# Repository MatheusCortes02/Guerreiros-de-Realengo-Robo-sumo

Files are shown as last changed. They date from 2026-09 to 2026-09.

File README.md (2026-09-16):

# Guerreiros de Realengo · robô de mini sumô

Robô **autônomo** de mini sumô (base de até 10 × 10 cm e até 500 g) do grupo **Guerreiros de Realengo** para a **InovaWeek da UVV**. Ninguém dirige o robô: o juiz dá o **START** e o **STOP** pelo controle, e ele procura o adversário e ataca sozinho.

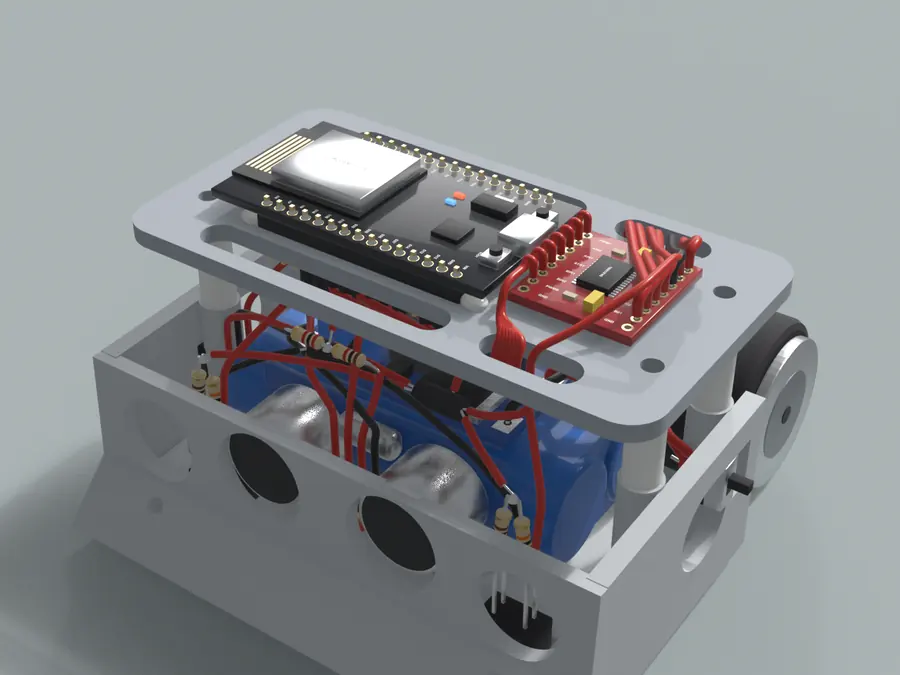
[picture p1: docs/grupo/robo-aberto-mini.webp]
Robô aberto: ESP32 e ponte H em cima da plataforma, fiação embaixo


## Manual de montagem

### [matheuscortes02.github.io/Guerreiros-de-Realengo-Robo-sumo/](https://matheuscortes02.github.io/Guerreiros-de-Realengo-Robo-sumo/)

O site é um **manual no estilo LEGO**, feito para ser seguido na bancada pelo celular:

- **69 passos em 13 blocos**, uma ação por passo;
- **blocos em cards**: entre num bloco e passe os passos um por tela, com botões grandes, deslizar para o lado e continuar de onde parou;
- a primeira tela de cada bloco mostra **os fios que ele usa, já com o tamanho de corte**;
- em cada passo, a **imagem do Blender** com a peça em tamanho real, o **número de cada fio** em cima dele e uma **lupa** com o detalhe;
- avisos do que **queima** se ligar errado e o que **conferir com o multímetro** antes de seguir;
- **vídeo da montagem** com capítulos por bloco, **lista de corte**, **ligações por peça** e **achar fio** pelo número da fita;
- duas versões: a **padrão**, com fios coloridos e tudo soldado do zero ([index.html](https://matheuscortes02.github.io/Guerreiros-de-Realengo-Robo-sumo/)), e a **do grupo**, só com fio vermelho e preto e com sonar, receptor e motores já soldados ([grupo.html](https://matheuscortes02.github.io/Guerreiros-de-Realengo-Robo-sumo/grupo.html));
- **português e inglês** pelas bandeiras no topo ([en.html](https://matheuscortes02.github.io/Guerreiros-de-Realengo-Robo-sumo/en.html) · [grupo-en.html](https://matheuscortes02.github.io/Guerreiros-de-Realengo-Robo-sumo/grupo-en.html)) e **tema claro e escuro** pelo ícone de sol e lua.

### Manual em texto para perguntar a um chat

A pasta [`docs/montagem-texto/`](docs/montagem-texto/) tem o mesmo manual em texto puro, gerado das mesmas fontes do site, para baixar o ZIP do repositório e enviar a um chat de IA no dia da montagem:

| Arquivo | Conteúdo |
|---|---|
| `00-LEIA-PRIMEIRO.txt` | como usar, instruções para o assistente, convenções, onde fica cada peça, alimentação, regras e pontos não confirmados |
| `01-montagem-versao-colorida.txt` | passo a passo completo da versão colorida, com imagem, peças, fio a fio (de onde, para onde, corte, caminho), avisos e conferências |
| `02-montagem-versao-grupo.txt` | o mesmo para a versão do grupo (fio vermelho e preto; sonar, receptor e motores já soldados) |
| `03-fios-lista-completa.txt` | os 36 fios com cor em cada versão, bitola, corte e passos em que aparecem |
| `04-ligacoes-por-peca.txt` | cada peça furo por furo e os 30 pinos do ESP32 contados da ponta do USB |
| `05-conferencias-multimetro.txt` | o que tem que apitar, o que não pode apitar e as tensões da primeira vez ligado |
| `06-firmware-e-gravacao.txt` | pinos do código, gravação, modo teste e modo luta |

## Equipe

Eduardo Nascimento · Gabriel da Silva · Gustavo Nunes · Kaike Panetto · Matheus Cortes

## Como o robô está montado

| Onde | O que fica |
|---|---|
| Frente, embaixo | 2 sensores de borda **TCRT5000 de 4 pernas**, colados nas janelas do piso |
| Frente | sonar **HC-SR04** nos dois furos do meio |
| Lateral direita | receptor do juiz **dentro do furo redondo**, bolinha para fora (lado oposto da chave) |
| Baia | bateria 2S 7,4 V com velcro · regulador **LM2596 colado em cima da bateria** |
| Lateral esquerda | chave deslizante **SS12D00** (3 pinos) |
| Trás | caixa com 2 motores N20 e rodas |
| Plataforma (**+17 mm**: espaçador de 12 mm com um de 5 mm em cima) | **ponte H TB6612** à esquerda · **ESP32** à direita, **apoiado na plataforma com os pinos atravessando dois rasgos** e o **USB virado para a esquerda** |

Esquerda e direita são sempre do robô: sonar apontando para longe de você.

### Alimentação

- **Bateria (+)** vai por dois caminhos: fio **3** direto ao **VM da ponte H** (motores) e fio **1** ao pino do meio da chave.
- A chave **SS12D00 aguenta 0,5 A**, por isso liga **só a eletrônica**: fio **2** até o IN+ do LM2596. A eletrônica puxa uns 0,2 A; os motores, até 3 A, não passam por ela.
- **LM2596** ajustado em **5,00 V** alimenta o VIN do ESP32 (fio 10) e o sonar (fio 12).
- O **3V3 do ESP32** vai a uma **emenda amarela** (fio 14) que alimenta os dois sensores de borda, o receptor e o VCC da ponte H.
- **GND** não é um fio só: o − da bateria vai à ponte H (4) e ao LM2596 (5); a saída do LM2596 vai ao ESP32 (11) e ao sonar (13); o outro GND do ESP32 vai a uma **emenda preta** (15) com os sensores, o receptor e o divisor do sonar.
- Com o cabo USB ligado, a chave fica em **DESLIGA**. Para guardar o robô, desconecte a bateria.

### Os 16 pinos usados no ESP32

Cada fio é soldado **na ponta do pino, por baixo da plataforma**, com termorretrátil. Por baixo não aparece nenhum nome: conte a partir da ponta do USB (o 1º da fileira da frente é o VIN; o 1º da de trás, o 3V3). Os 7 fios da ponte H descem pelo rasgo R2.

| Pino | Fileira | Posição a partir do USB | Fio | Vem de |
|---|---|---|---|---|
| VIN | frente (EN … VIN) | 1º | 10 | LM2596 · OUT+ |
| GND | frente (EN … VIN) | 2º | 11 | LM2596 · OUT− |
| D13 | frente (EN … VIN) | 3º | 31 | ponte H · STBY |
| D14 | frente (EN … VIN) | 5º | 34 | ponte H · PWMB |
| D27 | frente (EN … VIN) | 6º | 29 | ponte H · AIN2 |
| D26 | frente (EN … VIN) | 7º | 30 | ponte H · AIN1 |
| D25 | frente (EN … VIN) | 8º | 28 | ponte H · PWMA |
| D33 | frente (EN … VIN) | 9º | 33 | ponte H · BIN2 |
| D32 | frente (EN … VIN) | 10º | 32 | ponte H · BIN1 |
| D35 | frente (EN … VIN) | 11º | 24 | sensor direito · perna C |
| D34 | frente (EN … VIN) | 12º | 23 | sensor esquerdo · perna C |
| 3V3 | trás (D23 … 3V3) | 1º | 14 | emenda amarela |
| GND | trás (D23 … 3V3) | 2º | 15 | emenda preta |
| D5 | trás (D23 … 3V3) | 8º | 25 | sonar · TRIG |
| D18 | trás (D23 … 3V3) | 9º | 26B | resistor 1 kΩ |
| D19 | trás (D23 … 3V3) | 10º | 27 | receptor · OUT |

### Lista de corte

Comprimentos medidos no modelo 3D com a disposição real e com sobra (caminho + 15% + 20 mm; +40 mm nos fios que ligam a baia à plataforma, para dar para soldar com a plataforma virada). Total: **1050 mm de 22 AWG** e **2660 mm de 26 AWG**.

| Fio | Cor | Bitola | Corte | De | Para | Passa por |
|---|---|---|---|---|---|---|
| 1 | vermelho | 22 AWG | 60 mm | conector da bateria · + | chave · COM | embaixo da plataforma |
| 2 | vermelho | 22 AWG | 60 mm | chave · P1 | LM2596 · IN+ | embaixo da plataforma |
| 3 | vermelho | 22 AWG | 120 mm | conector da bateria · + | ponte H · VM | sobe pelo rasgo R4 |
| 4 | preto | 22 AWG | 120 mm | conector da bateria · − | ponte H · GND | sobe pelo rasgo R4 |
| 5 | preto | 22 AWG | 50 mm | conector da bateria · − | LM2596 · IN− | embaixo da plataforma |
| 6 | cinza | 22 AWG | 160 mm | motor esquerdo | ponte H · A01 | furo Ø6 da tampa e rasgo R4 |
| 7 | cinza | 22 AWG | 160 mm | motor esquerdo | ponte H · A02 | furo Ø6 da tampa e rasgo R4 |
| 8 | branco | 22 AWG | 160 mm | motor direito | ponte H · B01 | furo Ø6 da tampa e rasgo R4 |
| 9 | branco | 22 AWG | 160 mm | motor direito | ponte H · B02 | furo Ø6 da tampa e rasgo R4 |
| 10 | laranja | 26 AWG | 130 mm | LM2596 · OUT+ | ESP32 · VIN | sobe por baixo da plataforma até a ponta do pino |
| 11 | preto | 26 AWG | 120 mm | LM2596 · OUT− | ESP32 · GND | sobe por baixo da plataforma até a ponta do pino |
| 12 | laranja | 26 AWG | 100 mm | LM2596 · OUT+ | sonar · VCC | embaixo da plataforma |
| 13 | preto | 26 AWG | 100 mm | LM2596 · OUT− | sonar · GND | embaixo da plataforma |
| 14 | amarelo | 26 AWG | 110 mm | ESP32 · 3V3 | emenda amarela | sobe por baixo da plataforma até a ponta do pino |
| 15 | preto | 26 AWG | 110 mm | ESP32 · GND | emenda preta | sobe por baixo da plataforma até a ponta do pino |
| 16 | amarelo | 26 AWG | 50 mm | emenda amarela | resistores do sensor esquerdo | embaixo da plataforma |
| 17 | amarelo | 26 AWG | 70 mm | emenda amarela | resistores do sensor direito | embaixo da plataforma |
| 18 | amarelo | 26 AWG | 100 mm | emenda amarela | receptor · VCC | embaixo da plataforma |
| 19 | amarelo | 26 AWG | 130 mm | emenda amarela | ponte H · VCC | sobe pelo rasgo R2 |
| 20 | preto | 26 AWG | 80 mm | emenda preta | sensor esquerdo · perna K | embaixo da plataforma |
| 21 | preto | 26 AWG | 50 mm | emenda preta | sensor direito · perna K | embaixo da plataforma |
| 22 | preto | 26 AWG | 70 mm | emenda preta | receptor · GND | embaixo da plataforma |
| 23 | branco | 26 AWG | 150 mm | sensor esquerdo · perna C | ESP32 · D34 | sobe por baixo da plataforma até a ponta do pino |
| 24 | cinza | 26 AWG | 110 mm | sensor direito · perna C | ESP32 · D35 | sobe por baixo da plataforma até a ponta do pino |
| 25 | verde | 26 AWG | 150 mm | sonar · TRIG | ESP32 · D5 | sobe por baixo da plataforma até a ponta do pino |
| 26A | azul | 26 AWG | 70 mm | sonar · ECHO | resistor 1 kΩ | embaixo da plataforma |
| 26B | azul | 26 AWG | 110 mm | resistor 1 kΩ | ESP32 · D18 | sobe por baixo da plataforma até a ponta do pino |
| 26C | preto | 26 AWG | 40 mm | resistor 2 kΩ | emenda preta | embaixo da plataforma |
| 27 | roxo | 26 AWG | 130 mm | receptor · OUT | ESP32 · D19 | sobe por baixo da plataforma até a ponta do pino |
| 28 | marrom | 26 AWG | 110 mm | ponte H · PWMA | ESP32 · D25 | desce pelo rasgo R2 e sobe por baixo até a ponta do pino |
| 29 | azul | 26 AWG | 100 mm | ponte H · AIN2 | ESP32 · D27 | desce pelo rasgo R2 e sobe por baixo até a ponta do pino |
| 30 | verde | 26 AWG | 100 mm | ponte H · AIN1 | ESP32 · D26 | desce pelo rasgo R2 e sobe por baixo até a ponta do pino |
| 31 | roxo | 26 AWG | 90 mm | ponte H · STBY | ESP32 · D13 | desce pelo rasgo R2 e sobe por baixo até a ponta do pino |
| 32 | verde | 26 AWG | 100 mm | ponte H · BIN1 | ESP32 · D32 | desce pelo rasgo R2 e sobe por baixo até a ponta do pino |
| 33 | azul | 26 AWG | 100 mm | ponte H · BIN2 | ESP32 · D33 | desce pelo rasgo R2 e sobe por baixo até a ponta do pino |
| 34 | marrom | 26 AWG | 80 mm | ponte H · PWMB | ESP32 · D14 | desce pelo rasgo R2 e sobe por baixo até a ponta do pino |

## Firmware

Código em [`firmware/guerreiros_de_realengo/guerreiros_de_realengo.ino`](firmware/guerreiros_de_realengo/guerreiros_de_realengo.ino). Arduino IDE com a placa **esp32** da Espressif e a biblioteca **IRremote**; placa **DOIT ESP32 DEVKIT V1**. Pinos: ponte H em D25, D26, D27 (motor esquerdo), D14, D32, D33 (motor direito) e D13 (STBY); sonar em D5 e D18; sensores de borda em D34 e D35; receptor em D19.

Primeira gravação com `MODO_TESTE = true`: lê os códigos do controle do juiz, mostra sensores e sonar e gira cada motor pelas teclas `e` e `d`, com o robô no ar. Depois `MODO_TESTE = false`.

## Impressão 3D

| Placa | Arquivo | Conteúdo |
|---|---|---|
| 1 | `impressao/IMPRESSAO-1-chassi` (.stl ou .3mf) | chassi |
| 2 | `impressao/IMPRESSAO-2-restante` (.stl ou .3mf) | capô (já invertido), plataforma, caixa de motor e tampa |

PLA, camada 0,2 mm, 4 perímetros, 25%, sem suporte, z-hop ligado na placa 2.

## O que tem neste repositório

```
index.html                  manual de montagem (GitHub Pages)
docs/manual/                imagens do manual (webp)
firmware/                   código do ESP32
impressao/                  arquivos para o fatiador
modelo-3d/robo-sumo.blend   cena do Blender com a disposição e os fios traçados
```

---

Projeto acadêmico do grupo **Guerreiros de Realengo** para a InovaWeek da UVV. O chassi foi derivado de um modelo STL de terceiros (*Sarı Yazma Tasarım V2*), reescalado e adaptado; confira a licença do original antes de redistribuir fora do contexto acadêmico.

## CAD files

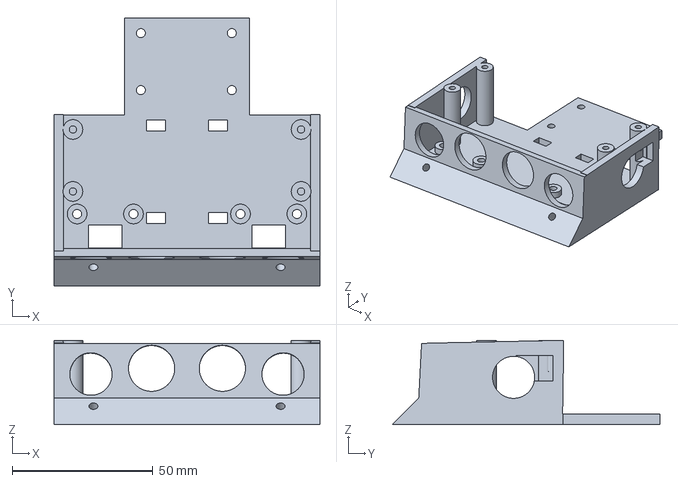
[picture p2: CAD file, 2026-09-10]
impressao/IMPRESSAO-1-chassi.3mf
94.4 x 95.0 x 30.0 mm

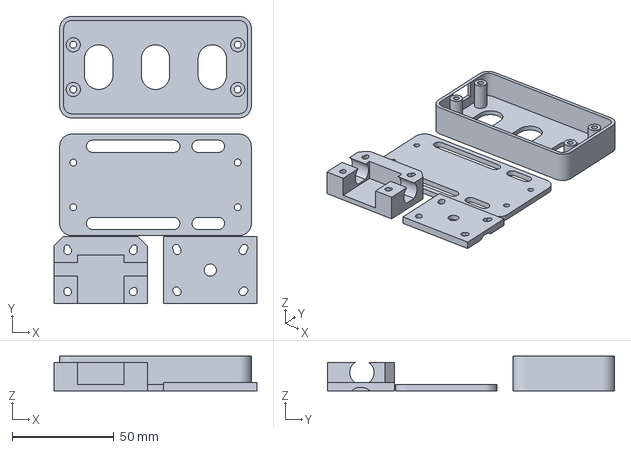
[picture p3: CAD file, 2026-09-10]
impressao/IMPRESSAO-2-restante.3mf
100.0 x 141.5 x 17.0 mm

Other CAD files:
impressao/IMPRESSAO-1-chassi.stl
impressao/IMPRESSAO-2-restante.stl
modelo-3d/robo-sumo.blend

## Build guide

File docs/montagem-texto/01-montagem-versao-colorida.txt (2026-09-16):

====================================================================================================
GUERREIROS DE REALENGO · MANUAL DE MONTAGEM EM TEXTO · VERSÃO COLORIDA (padrão do site, fios coloridos, tudo soldado do zero)
====================================================================================================
Mesmo conteúdo da página
https://matheuscortes02.github.io/Guerreiros-de-Realengo-Robo-sumo/index.html (69 passos em 13
blocos). A numeração dos passos é a mesma do site. As imagens citadas estão no ZIP, nas pastas
indicadas. Esquerda e direita são sempre DO ROBÔ: sonar apontando para longe de você. Leia antes o
00-LEIA-PRIMEIRO.txt.

ÍNDICE
  Bloco  1 · Antes de começar · passos 1 a 4
  Bloco  2 · Sensores de borda · passos 5 a 14
  Bloco  3 · Sonar HC-SR04 · passos 15 a 21
  Bloco  4 · Receptor do juiz · passos 22 a 25
  Bloco  5 · Motores e rodas · passos 26 a 30
  Bloco  6 · Bateria, conector e chave · passos 31 a 37
  Bloco  7 · Regulador LM2596 · passos 38 a 41
  Bloco  8 · Emendas 3V3 e GND · passos 42 a 44
  Bloco  9 · Plataforma: ESP32 e ponte H · passos 45 a 52
  Bloco 10 · Plataforma no robô · passos 53 a 56
  Bloco 11 · Ponte H: energia e motores · passos 57 a 62
  Bloco 12 · Conferir e fechar · passos 63 a 66
  Bloco 13 · Programar e lutar · passos 67 a 69

####################################################################################################
BLOCO 1 · ANTES DE COMEÇAR · passos 1 a 4
####################################################################################################
Separe tudo, confira os resistores e aprenda a emendar. Cada bloco mostra, na primeira tela, os fios
que ele usa.
Imagem de capa: docs/manual/preparo-pecas.webp

----------------------------------------------------------------------------------------------------
PASSO 1 de 69 · Bloco 1 · Separe as peças
----------------------------------------------------------------------------------------------------
Imagem: docs/manual/preparo-pecas.webp
Na imagem: etiquetas “ESP32”, “ponte H”, “LM2596”, “HC-SR04”, “bateria”, “2 × TCRT5000”, “receptor”,
“2 × motor”, “chave SS12D00”, “conector”, “6 resistores”.
O que fazer:
  * Além disso: fio flexível 22 AWG e 26 AWG, termorretrátil, fita crepe, fita dupla-face, cola
    quente, velcro, termorretrátil fino de 1,5 mm (pinos do ESP32), 4 espaçadores de 12 mm e 4 de 5
    mm (plataforma), 4 parafusos M3 × 25 com porca e 4 M3 × 45.
CONFIRA: Ferramentas: ferro de solda, estanho com fluxo, alicate de corte, desencapador, multímetro,
    isqueiro ou soprador.
Quando terminar: passo 1 feito. Próximo: passo 2.

----------------------------------------------------------------------------------------------------
PASSO 2 de 69 · Bloco 1 · Confira os resistores
----------------------------------------------------------------------------------------------------
Imagem: docs/manual/preparo-resistores.webp
Na imagem: etiquetas “100 Ω · 2 peças”, “10 kΩ · 2 peças”, “1 kΩ · 1 peça”, “2 kΩ · 1 peça”.
Peças deste passo:
  - 2× 100 Ω — marrom · preto · marrom
  - 2× 10 kΩ — marrom · preto · laranja
  - 1× 1 kΩ — marrom · preto · vermelho
  - 1× 2 kΩ — vermelho · preto · vermelho
O que fazer:
  * 100 Ω e 10 kΩ são quase iguais: só muda a terceira faixa. Meça cada um com o multímetro e separe
    em grupos.
ATENÇÃO: Trocar o 100 Ω pelo 10 kΩ não queima, mas o sensor de borda para de funcionar.
Quando terminar: passo 2 feito. Próximo: passo 3.

----------------------------------------------------------------------------------------------------
PASSO 3 de 69 · Bloco 1 · Numere cada fio
----------------------------------------------------------------------------------------------------
Imagem: docs/manual/preparo-fios.webp
O que fazer:
  * Cor obrigatória só na alimentação: vermelho 7,4 V, laranja 5 V, amarelo 3,3 V, preto GND. Sinal
    pode ser de qualquer cor, mas cole a fita com o número nas duas pontas.
  * Corte cada fio no tamanho que aparece na primeira tela do bloco onde ele entra (e na lista de
    corte). As medidas já têm sobra.
Quando terminar: passo 3 feito. Próximo: passo 4.

----------------------------------------------------------------------------------------------------
PASSO 4 de 69 · Bloco 1 · Como emendar dois fios
----------------------------------------------------------------------------------------------------
Imagem: docs/manual/preparo-solda.webp
Na imagem: etiquetas “1”, “2”, “3”, “4”.
O que fazer:
  * 1 Desencape 4 mm. 2 Passe o termorretrátil antes, torça as pontas e estanhe.
  * 3 Solde com 2 a 3 segundos de ferro, sem mexer até esfriar. 4 Puxe o tubo por cima e aqueça.
CONFIRA: Puxe de leve: a emenda não pode soltar. Solda boa é lisa e brilhante.
Quando terminar: passo 4 feito. Próximo: passo 5.

####################################################################################################
BLOCO 2 · SENSORES DE BORDA · passos 5 a 14
####################################################################################################
Dois TCRT5000 de 4 perninhas. Monte o esquerdo; o direito é igual, só muda o número dos fios.
Imagem de capa: docs/manual/tcrt-t8.webp

FIOS QUE ENTRAM NESTE BLOCO (corte e numere com fita nas duas pontas antes de começar)
  - Fio 16 — amarelo — 26 AWG — corte com 50 mm
      de: emenda 3V3 (5 fios torcidos e soldados juntos)
      para: ponta de cima dos dois resistores (100 Ω e 10 kΩ) do sensor esquerdo, torcidas juntas
  - Fio 17 — amarelo — 26 AWG — corte com 70 mm
      de: emenda 3V3 (5 fios torcidos e soldados juntos)
      para: ponta de cima dos dois resistores (100 Ω e 10 kΩ) do sensor direito, torcidas juntas
  - Fio 20 — preto — 26 AWG — corte com 80 mm
      de: emenda GND (5 fios torcidos e soldados juntos)
      para: sensor esquerdo (TCRT5000), perna K
  - Fio 21 — preto — 26 AWG — corte com 50 mm
      de: emenda GND (5 fios torcidos e soldados juntos)
      para: sensor direito (TCRT5000), perna K
  - Fio 23 — branco — 26 AWG — corte com 150 mm
      de: sensor esquerdo (TCRT5000), perna C
      para: ESP32, pino D34 (fileira da FRENTE, a do EN…VIN, lado do sonar; 12º pino contando a partir da ponta do USB)
  - Fio 24 — cinza — 26 AWG — corte com 110 mm
      de: sensor direito (TCRT5000), perna C
      para: ESP32, pino D35 (fileira da FRENTE, a do EN…VIN, lado do sonar; 11º pino contando a partir da ponta do USB)

----------------------------------------------------------------------------------------------------
PASSO 5 de 69 · Bloco 2 · Ache as pernas A, K, C e E
----------------------------------------------------------------------------------------------------
Imagem: docs/manual/tcrt-t0.webp
Lupa (detalhe ampliado, no canto da imagem): docs/manual/tcrt-t0-lupa.webp
Na imagem: etiquetas “A”, “K”, “C”, “E”, “lente azul”, “lente preta”.
Peças deste passo:
  - 1× TCRT5000 — 4 perninhas
O que fazer:
  * Debaixo da lente azul ficam A e K. Debaixo da lente preta, C e E. Na mesma fileira ficam A e C.
CONFIRA: Multímetro no modo diodo, vermelha numa perna do lado azul e preta na outra: por volta de
    1,1 V quer dizer vermelha no A. Marque o A.
Quando terminar: passo 5 feito. Próximo: passo 6.

----------------------------------------------------------------------------------------------------
PASSO 6 de 69 · Bloco 2 · 100 Ω na perna A
----------------------------------------------------------------------------------------------------
Imagem: docs/manual/tcrt-t1.webp
Na imagem: etiquetas “100 Ω”.
Peças deste passo:
  - 1× Resistor 100 Ω — marrom · preto · marrom
  - Termorretrátil — pedaços de 1 a 2 cm
O que fazer:
  * Termorretrátil na perna A, encoste uma perna do 100 Ω ao lado e solde.
ATENÇÃO: Sem esse resistor, o LED do sensor queima na primeira vez que ligar.
Quando terminar: passo 6 feito. Próximo: passo 7.

----------------------------------------------------------------------------------------------------
PASSO 7 de 69 · Bloco 2 · 10 kΩ na perna C
----------------------------------------------------------------------------------------------------
Imagem: docs/manual/tcrt-t2.webp
Na imagem: etiquetas “10 kΩ”.
Peças deste passo:
  - 1× Resistor 10 kΩ — marrom · preto · laranja
  - Termorretrátil — pedaços de 1 a 2 cm
O que fazer:
  * Mesma coisa na perna C com o 10 kΩ. Incline os dois resistores até as pontas de cima se tocarem.
Quando terminar: passo 7 feito. Próximo: passo 8.

----------------------------------------------------------------------------------------------------
PASSO 8 de 69 · Bloco 2 · Una as pernas K e E
----------------------------------------------------------------------------------------------------
Imagem: docs/manual/tcrt-t3.webp
Na imagem: etiquetas “ponte”.
O que fazer:
  * Com uma sobra de perna de resistor, faça uma ponte entre K e E e solde nas duas.
CONFIRA: A ponte não pode encostar em A nem em C.
Quando terminar: passo 8 feito. Próximo: passo 9.

----------------------------------------------------------------------------------------------------
PASSO 9 de 69 · Bloco 2 · Fio 16 na ponta dos resistores
----------------------------------------------------------------------------------------------------
Imagem: docs/manual/tcrt-t4.webp
Na imagem: círculo com o número do fio 16.
Peças deste passo:
  - Fio 16 — amarelo — 26 AWG — corte com 50 mm
  - Termorretrátil — pedaços de 1 a 2 cm
O que fazer:
  * Torça as pontas de cima dos dois resistores com a ponta do fio 16 (amarelo, 3,3 V) e solde.
Ligações deste passo, fio a fio:
  - Fio 16: (também aparece no passo 42: uma ponta é soldada aqui e a outra lá)
      uma ponta: emenda 3V3 (5 fios torcidos e soldados juntos)
      outra ponta: ponta de cima dos dois resistores (100 Ω e 10 kΩ) do sensor esquerdo, torcidas
        juntas
      caminho: embaixo da plataforma
      observação: chega na junção dos dois resistores do TCRT esquerdo
Quando terminar: passo 9 feito. Próximo: passo 10.

----------------------------------------------------------------------------------------------------
PASSO 10 de 69 · Bloco 2 · Fio 23 na perna C
----------------------------------------------------------------------------------------------------
Imagem: docs/manual/tcrt-t5.webp
Na imagem: círculo com o número do fio 23.
Peças deste passo:
  - Fio 23 — branco — 26 AWG — corte com 150 mm
O que fazer:
  * Solde o fio 23 (branco, sinal) na perna C, no ponto onde já está o 10 kΩ.
Ligações deste passo, fio a fio:
  - Fio 23: (também aparece no passo 54: uma ponta é soldada aqui e a outra lá)
      uma ponta: sensor esquerdo (TCRT5000), perna C
      outra ponta: ESP32, pino D34 (fileira da FRENTE, a do EN…VIN, lado do sonar; 12º pino contando
        a partir da ponta do USB)
      caminho: sobe por baixo da plataforma até a ponta do pino
      observação: junto com o 10 kΩ na perna C
Quando terminar: passo 10 feito. Próximo: passo 11.

----------------------------------------------------------------------------------------------------
PASSO 11 de 69 · Bloco 2 · Fio 20 na ponte K–E
----------------------------------------------------------------------------------------------------
Imagem: docs/manual/tcrt-t6.webp
Na imagem: círculo com o número do fio 20.
Peças deste passo:
  - Fio 20 — preto — 26 AWG — corte com 80 mm
O que fazer:
  * Solde o fio 20 (preto, GND) no meio da ponte entre K e E.
Ligações deste passo, fio a fio:
  - Fio 20: (também aparece no passo 43: uma ponta é soldada aqui e a outra lá)
      uma ponta: emenda GND (5 fios torcidos e soldados juntos)
      outra ponta: sensor esquerdo (TCRT5000), perna K
      caminho: embaixo da plataforma
      observação: chega na ponte entre as pernas K e E
Quando terminar: passo 11 feito. Próximo: passo 12.

----------------------------------------------------------------------------------------------------
PASSO 12 de 69 · Bloco 2 · Termorretrátil em tudo
----------------------------------------------------------------------------------------------------
Imagem: docs/manual/tcrt-t7.webp
O que fazer:
  * Puxe os tubos por cima de cada solda e aqueça. Nenhum metal à mostra.
CONFIRA: Multímetro no bipe: entre o fio 16 e o fio 20 não pode apitar.
Quando terminar: passo 12 feito. Próximo: passo 13.

----------------------------------------------------------------------------------------------------
PASSO 13 de 69 · Bloco 2 · Monte o sensor direito igual · ×2
----------------------------------------------------------------------------------------------------
Imagem: docs/manual/tcrt-t8.webp
Na imagem: círculos com os números dos fios 16, 23, 20, 17, 24, 21; etiquetas “esquerdo”, “direito”.
Peças deste passo:
  - 1× TCRT5000
  - 1× Resistor 100 Ω — marrom · preto · marrom
  - 1× Resistor 10 kΩ — marrom · preto · laranja
  - Fio 17 — amarelo — 26 AWG — corte com 70 mm
  - Fio 24 — cinza — 26 AWG — corte com 110 mm
  - Fio 21 — preto — 26 AWG — corte com 50 mm
O que fazer:
  * Só mudam os fios: 17 no lugar do 16, 24 no lugar do 23 e 21 no lugar do 20.
Ligações deste passo, fio a fio:
  - Fio 17: (também aparece no passo 42: uma ponta é soldada aqui e a outra lá)
      uma ponta: emenda 3V3 (5 fios torcidos e soldados juntos)
      outra ponta: ponta de cima dos dois resistores (100 Ω e 10 kΩ) do sensor direito, torcidas
        juntas
      caminho: embaixo da plataforma
      observação: chega na junção dos dois resistores do TCRT direito
  - Fio 24: (também aparece no passo 54: uma ponta é soldada aqui e a outra lá)
      uma ponta: sensor direito (TCRT5000), perna C
      outra ponta: ESP32, pino D35 (fileira da FRENTE, a do EN…VIN, lado do sonar; 11º pino contando
        a partir da ponta do USB)
      caminho: sobe por baixo da plataforma até a ponta do pino
      observação: junto com o 10 kΩ na perna C
  - Fio 21: (também aparece no passo 43: uma ponta é soldada aqui e a outra lá)
      uma ponta: emenda GND (5 fios torcidos e soldados juntos)
      outra ponta: sensor direito (TCRT5000), perna K
      caminho: embaixo da plataforma
      observação: chega na ponte entre as pernas K e E
Quando terminar: passo 13 feito. Próximo: passo 14.

----------------------------------------------------------------------------------------------------
PASSO 14 de 69 · Bloco 2 · Cole nas janelas do piso
----------------------------------------------------------------------------------------------------
Imagem: docs/manual/robo-tcrt.webp
Lupa (detalhe ampliado, no canto da imagem): docs/manual/robo-tcrt-baixo.webp
Peças deste passo:
  - Cola quente
  - Cartão de visita — calço de 0,3 mm
O que fazer:
  * Chassi em pé numa mesa lisa, cartão dentro da janela, sensor com as lentes para baixo até
    encostar no cartão. Cole só por cima.
  * O sensor dos fios 16, 23 e 20 vai na janela do lado esquerdo do robô.
CONFIRA: Esquerda e direita são do robô: sonar apontando para longe de você.
Quando terminar: passo 14 feito. Próximo: passo 15.

####################################################################################################
BLOCO 3 · SONAR HC-SR04 · passos 15 a 21
####################################################################################################
Quatro fios e um divisor com dois resistores, que protege o ESP32 dos 5 V do sonar.
Imagem de capa: docs/manual/sonar-h6.webp

FIOS QUE ENTRAM NESTE BLOCO (corte e numere com fita nas duas pontas antes de começar)
  - Fio 12 — laranja — 26 AWG — corte com 100 mm
      de: LM2596, furo OUT+
      para: sonar HC-SR04, pino VCC
  - Fio 13 — preto — 26 AWG — corte com 100 mm
      de: LM2596, furo OUT−
      para: sonar HC-SR04, pino GND
  - Fio 25 — verde — 26 AWG — corte com 150 mm
      de: sonar HC-SR04, pino TRIG
      para: ESP32, pino D5 (fileira de TRÁS, a do D23…3V3; 8º pino contando a partir da ponta do USB)
  - Fio 26A — azul — 26 AWG — corte com 70 mm
      de: sonar HC-SR04, pino ECHO
      para: resistor 1 kΩ do divisor do sonar (perna emendada no fio 26A)
  - Fio 26B — azul — 26 AWG — corte com 110 mm
      de: nó do divisor do sonar (perna do 1 kΩ onde também estão o 2 kΩ e o fio 26B)
      para: ESP32, pino D18 (fileira de TRÁS, a do D23…3V3; 9º pino contando a partir da ponta do USB)
  - Fio 26C — preto — 26 AWG — corte com 40 mm
      de: resistor 2 kΩ do divisor do sonar (perna livre, onde vai o fio 26C)
      para: emenda GND (5 fios torcidos e soldados juntos)

----------------------------------------------------------------------------------------------------
PASSO 15 de 69 · Bloco 3 · Ache os 4 pinos
----------------------------------------------------------------------------------------------------
Imagem: docs/manual/sonar-h1.webp
Lupa (detalhe ampliado, no canto da imagem): docs/manual/sonar-h1-lupa.webp
Na imagem: etiquetas “Vcc”, “Trig”, “Echo”, “Gnd”.
Peças deste passo:
  - 1× HC-SR04
O que fazer:
  * Transdutores para cima, pinos para você: Vcc, Trig, Echo, Gnd. Se forem compridos, corte
    deixando 3 mm.
Quando terminar: passo 15 feito. Próximo: passo 16.

----------------------------------------------------------------------------------------------------
PASSO 16 de 69 · Bloco 3 · Fios 12 e 13: alimentação
----------------------------------------------------------------------------------------------------
Imagem: docs/manual/sonar-h2.webp
Na imagem: círculos com os números dos fios 12, 13.
Peças deste passo:
  - Fio 12 — laranja — 26 AWG — corte com 100 mm
  - Fio 13 — preto — 26 AWG — corte com 100 mm
  - Termorretrátil — pedaços de 1 a 2 cm
O que fazer:
  * Fio 12 (laranja, 5 V) no Vcc. Fio 13 (preto) no Gnd.
Ligações deste passo, fio a fio:
  - Fio 12: (também aparece no passo 41: uma ponta é soldada aqui e a outra lá)
      uma ponta: LM2596, furo OUT+
      outra ponta: sonar HC-SR04, pino VCC
      caminho: embaixo da plataforma
      observação: divide o furo OUT+ com o fio 10
  - Fio 13: (também aparece no passo 41: uma ponta é soldada aqui e a outra lá)
      uma ponta: LM2596, furo OUT−
      outra ponta: sonar HC-SR04, pino GND
      caminho: embaixo da plataforma
      observação: divide o furo OUT− com o fio 11
ATENÇÃO: Invertendo Vcc e Gnd o sonar queima.
Quando terminar: passo 16 feito. Próximo: passo 17.

----------------------------------------------------------------------------------------------------
PASSO 17 de 69 · Bloco 3 · Fios 25 e 26A: sinais
----------------------------------------------------------------------------------------------------
Imagem: docs/manual/sonar-h3.webp
Na imagem: círculos com os números dos fios 25, 26A.
Peças deste passo:
  - Fio 25 — verde — 26 AWG — corte com 150 mm
  - Fio 26A — azul — 26 AWG — corte com 70 mm
  - Termorretrátil — pedaços de 1 a 2 cm
O que fazer:
  * Fio 25 no Trig. Fio 26A no Echo.
Ligações deste passo, fio a fio:
  - Fio 25: (também aparece no passo 55: uma ponta é soldada aqui e a outra lá)
      uma ponta: sonar HC-SR04, pino TRIG
      outra ponta: ESP32, pino D5 (fileira de TRÁS, a do D23…3V3; 8º pino contando a partir da ponta
        do USB)
      caminho: sobe por baixo da plataforma até a ponta do pino
  - Fio 26A:
      uma ponta: sonar HC-SR04, pino ECHO
      outra ponta: resistor 1 kΩ do divisor do sonar (perna emendada no fio 26A)
      caminho: embaixo da plataforma
      observação: ECHO até o 1 kΩ (ainda 5 V)
Quando terminar: passo 17 feito. Próximo: passo 18.

----------------------------------------------------------------------------------------------------
PASSO 18 de 69 · Bloco 3 · 1 kΩ na ponta do fio 26A
----------------------------------------------------------------------------------------------------
Imagem: docs/manual/sonar-h4.webp
Na imagem: etiquetas “1 kΩ”.
Peças deste passo:
  - 1× Resistor 1 kΩ — marrom · preto · vermelho
  - Termorretrátil — pedaços de 1 a 2 cm
O que fazer:
  * Emende o 1 kΩ na ponta solta do fio 26A, como uma emenda de dois fios.
Quando terminar: passo 18 feito. Próximo: passo 19.

----------------------------------------------------------------------------------------------------
PASSO 19 de 69 · Bloco 3 · O nó: 2 kΩ e fio 26B
----------------------------------------------------------------------------------------------------
Imagem: docs/manual/sonar-h5.webp
Na imagem: círculo com o número do fio 26B; etiquetas “2 kΩ”.
Peças deste passo:
  - 1× Resistor 2 kΩ — vermelho · preto · vermelho
  - Fio 26B — azul — 26 AWG — corte com 110 mm
  - Termorretrátil — pedaços de 1 a 2 cm
O que fazer:
  * Na outra perna do 1 kΩ, solde juntos uma perna do 2 kΩ e o fio 26B. O 26B leva o sinal ao ESP32.
Ligações deste passo, fio a fio:
  - Fio 26B: (também aparece no passo 55: uma ponta é soldada aqui e a outra lá)
      uma ponta: nó do divisor do sonar (perna do 1 kΩ onde também estão o 2 kΩ e o fio 26B)
      outra ponta: ESP32, pino D18 (fileira de TRÁS, a do D23…3V3; 9º pino contando a partir da
        ponta do USB)
      caminho: sobe por baixo da plataforma até a ponta do pino
      observação: sai do nó do divisor (já 3,3 V)
Quando terminar: passo 19 feito. Próximo: passo 20.

----------------------------------------------------------------------------------------------------
PASSO 20 de 69 · Bloco 3 · Fio 26C no 2 kΩ
----------------------------------------------------------------------------------------------------
Imagem: docs/manual/sonar-h6.webp
Na imagem: círculo com o número do fio 26C.
Peças deste passo:
  - Fio 26C — preto — 26 AWG — corte com 40 mm
  - Termorretrátil — pedaços de 1 a 2 cm
O que fazer:
  * Na perna livre do 2 kΩ, solde o fio 26C (preto). Ele vai na emenda GND do bloco 8.
    Termorretrátil em tudo.
Ligações deste passo, fio a fio:
  - Fio 26C: (também aparece no passo 43: uma ponta é soldada aqui e a outra lá)
      uma ponta: resistor 2 kΩ do divisor do sonar (perna livre, onde vai o fio 26C)
      outra ponta: emenda GND (5 fios torcidos e soldados juntos)
      caminho: embaixo da plataforma
      observação: do 2 kΩ até a emenda GND
ATENÇÃO: O fio 26B nunca vai direto no Echo: sem o divisor, o sinal chega com 5 V e estraga o pino
    do ESP32.
Quando terminar: passo 20 feito. Próximo: passo 21.

----------------------------------------------------------------------------------------------------
PASSO 21 de 69 · Bloco 3 · Encaixe na frente do chassi
----------------------------------------------------------------------------------------------------
Imagem: docs/manual/robo-hc.webp
Peças deste passo:
  - Cola quente
O que fazer:
  * Por dentro, encaixe os dois transdutores nos furos do meio da frente. Trave com cola quente na
    lateral da placa.
Quando terminar: passo 21 feito. Próximo: passo 22.

####################################################################################################
BLOCO 4 · RECEPTOR DO JUIZ · passos 22 a 25
####################################################################################################
Recebe START e STOP do juiz. Fica dentro do furo redondo da lateral DIREITA, oposta à chave.
Imagem de capa: docs/manual/receptor-i3.webp

FIOS QUE ENTRAM NESTE BLOCO (corte e numere com fita nas duas pontas antes de começar)
  - Fio 18 — amarelo — 26 AWG — corte com 100 mm
      de: emenda 3V3 (5 fios torcidos e soldados juntos)
      para: receptor do juiz, perna VCC
  - Fio 22 — preto — 26 AWG — corte com 70 mm
      de: emenda GND (5 fios torcidos e soldados juntos)
      para: receptor do juiz, perna GND
  - Fio 27 — roxo — 26 AWG — corte com 130 mm
      de: receptor do juiz, perna OUT
      para: ESP32, pino D19 (fileira de TRÁS, a do D23…3V3; 10º pino contando a partir da ponta do USB)

----------------------------------------------------------------------------------------------------
PASSO 22 de 69 · Bloco 4 · Ache as 3 pernas
----------------------------------------------------------------------------------------------------
Imagem: docs/manual/receptor-i1.webp
Na imagem: etiquetas “OUT”, “GND”, “VCC”, “S”, “+”, “−”.
Peças deste passo:
  - 1× VS1838B ou KY-022
O que fazer:
  * VS1838B, bolinha de frente: OUT, GND, VCC. KY-022: S, +, −. Siga o impresso na sua.
ATENÇÃO: O pino do meio muda: no VS1838B é GND, na KY-022 é +. Trocado, queima o receptor.
Quando terminar: passo 22 feito. Próximo: passo 23.

----------------------------------------------------------------------------------------------------
PASSO 23 de 69 · Bloco 4 · Dobre as pernas
----------------------------------------------------------------------------------------------------
Imagem: docs/manual/receptor-i2.webp
O que fazer:
  * Dobre as três pernas para trás logo abaixo do corpo e corte deixando 6 mm.
Quando terminar: passo 23 feito. Próximo: passo 24.

----------------------------------------------------------------------------------------------------
PASSO 24 de 69 · Bloco 4 · Fios 27, 22 e 18
----------------------------------------------------------------------------------------------------
Imagem: docs/manual/receptor-i3.webp
Na imagem: círculos com os números dos fios 27, 22, 18.
Peças deste passo:
  - Fio 27 — roxo — 26 AWG — corte com 130 mm
  - Fio 22 — preto — 26 AWG — corte com 70 mm
  - Fio 18 — amarelo — 26 AWG — corte com 100 mm
  - Termorretrátil — pedaços de 1 a 2 cm
O que fazer:
  * 27 no OUT · 22 no GND · 18 no VCC. Na KY-022: 27 no S, 18 no +, 22 no −.
Ligações deste passo, fio a fio:
  - Fio 27: (também aparece no passo 55: uma ponta é soldada aqui e a outra lá)
      uma ponta: receptor do juiz, perna OUT
      outra ponta: ESP32, pino D19 (fileira de TRÁS, a do D23…3V3; 10º pino contando a partir da
        ponta do USB)
      caminho: sobe por baixo da plataforma até a ponta do pino
  - Fio 22: (também aparece no passo 43: uma ponta é soldada aqui e a outra lá)
      uma ponta: emenda GND (5 fios torcidos e soldados juntos)
      outra ponta: receptor do juiz, perna GND
      caminho: embaixo da plataforma
  - Fio 18: (também aparece no passo 42: uma ponta é soldada aqui e a outra lá)
      uma ponta: emenda 3V3 (5 fios torcidos e soldados juntos)
      outra ponta: receptor do juiz, perna VCC
      caminho: embaixo da plataforma
ATENÇÃO: Receptor só no 3,3 V. Em 5 V, o sinal dele chega com 5 V no ESP32.
Quando terminar: passo 24 feito. Próximo: passo 25.

----------------------------------------------------------------------------------------------------
PASSO 25 de 69 · Bloco 4 · Encaixe no furo redondo da lateral direita
----------------------------------------------------------------------------------------------------
Imagem: docs/manual/robo-ir.webp
Lupa (detalhe ampliado, no canto da imagem): docs/manual/robo-ir-lupa.webp
Peças deste passo:
  - Cola quente
O que fazer:
  * Por dentro do chassi, empurre o receptor para dentro do furo redondo da lateral direita (lado
    oposto da chave), bolinha para fora. Trave com cola quente no corpo.
CONFIRA: Por fora do robô, você tem que ver a bolinha preta no meio do furo.
Quando terminar: passo 25 feito. Próximo: passo 26.

####################################################################################################
BLOCO 5 · MOTORES E RODAS · passos 26 a 30
####################################################################################################
Dois fios em cada motor antes de entrar na caixa.
Imagem de capa: docs/manual/robo-rodas.webp

FIOS QUE ENTRAM NESTE BLOCO (corte e numere com fita nas duas pontas antes de começar)
  - Fio 6 — cinza — 22 AWG — corte com 160 mm
      de: motor esquerdo, um dos dois terminais
      para: ponte H TB6612, furo A01 (fileira de energia, a do VM; 4º furo)
  - Fio 7 — cinza — 22 AWG — corte com 160 mm
      de: motor esquerdo, um dos dois terminais
      para: ponte H TB6612, furo A02 (fileira de energia, a do VM; 5º furo)
  - Fio 8 — branco — 22 AWG — corte com 160 mm
      de: motor direito, um dos dois terminais
      para: ponte H TB6612, furo B01 (fileira de energia, a do VM; 7º furo)
  - Fio 9 — branco — 22 AWG — corte com 160 mm
      de: motor direito, um dos dois terminais
      para: ponte H TB6612, furo B02 (fileira de energia, a do VM; 6º furo)

----------------------------------------------------------------------------------------------------
PASSO 26 de 69 · Bloco 5 · Fios nos motores
----------------------------------------------------------------------------------------------------
Imagem: docs/manual/motores-m1.webp
Na imagem: círculos com os números dos fios 6, 7, 8, 9; etiquetas “esquerdo”, “direito”.
Peças deste passo:
  - 2× Motor N20
  - Fio 6 — cinza — 22 AWG — corte com 160 mm
  - Fio 7 — cinza — 22 AWG — corte com 160 mm
  - Fio 8 — branco — 22 AWG — corte com 160 mm
  - Fio 9 — branco — 22 AWG — corte com 160 mm
O que fazer:
  * Motor esquerdo: fios 6 e 7. Motor direito: 8 e 9. Um fio em cada terminal. Motor não tem lado
    certo.
Ligações deste passo, fio a fio:
  - Fio 6: (também aparece no passo 60: uma ponta é soldada aqui e a outra lá)
      uma ponta: motor esquerdo, um dos dois terminais
      outra ponta: ponte H TB6612, furo A01 (fileira de energia, a do VM; 4º furo)
      caminho: furo Ø6 da tampa e rasgo R4
  - Fio 7: (também aparece no passo 60: uma ponta é soldada aqui e a outra lá)
      uma ponta: motor esquerdo, um dos dois terminais
      outra ponta: ponte H TB6612, furo A02 (fileira de energia, a do VM; 5º furo)
      caminho: furo Ø6 da tampa e rasgo R4
  - Fio 8: (também aparece no passo 61: uma ponta é soldada aqui e a outra lá)
      uma ponta: motor direito, um dos dois terminais
      outra ponta: ponte H TB6612, furo B01 (fileira de energia, a do VM; 7º furo)
      caminho: furo Ø6 da tampa e rasgo R4
  - Fio 9: (também aparece no passo 61: uma ponta é soldada aqui e a outra lá)
      uma ponta: motor direito, um dos dois terminais
      outra ponta: ponte H TB6612, furo B02 (fileira de energia, a do VM; 6º furo)
      caminho: furo Ø6 da tampa e rasgo R4
CONFIRA: Teste antes de fechar: encoste por 1 segundo os dois fios de um motor no + e no − da
    bateria. Ele tem que girar.
Quando terminar: passo 26 feito. Próximo: passo 27.

----------------------------------------------------------------------------------------------------
PASSO 27 de 69 · Bloco 5 · Isole a traseira
----------------------------------------------------------------------------------------------------
Imagem: docs/manual/motores-m2.webp
Na imagem: etiquetas “fita isolante”.
Peças deste passo:
  - Fita isolante
O que fazer:
  * Fita isolante na traseira de cada motor: os dois se encostam dentro da caixa.
ATENÇÃO: Terminal de um motor encostando no do outro dá curto na ponte H.
Quando terminar: passo 27 feito. Próximo: passo 28.

----------------------------------------------------------------------------------------------------
PASSO 28 de 69 · Bloco 5 · Motores na caixa
----------------------------------------------------------------------------------------------------
Imagem: docs/manual/robo-motores.webp
O que fazer:
  * Cada motor entra pela sua lateral, eixo para fora. O esquerdo pelo lado esquerdo do robô.
Quando terminar: passo 28 feito. Próximo: passo 29.

----------------------------------------------------------------------------------------------------
PASSO 29 de 69 · Bloco 5 · Tampa e parafusos
----------------------------------------------------------------------------------------------------
Imagem: docs/manual/robo-tampa.webp
Peças deste passo:
  - 4× Parafuso M3 × 25 — com porca
O que fazer:
  * Passe os 4 fios pelo furo do meio da tampa, encaixe a tampa e parafuse a caixa no chassi.
Quando terminar: passo 29 feito. Próximo: passo 30.

----------------------------------------------------------------------------------------------------
PASSO 30 de 69 · Bloco 5 · Rodas
----------------------------------------------------------------------------------------------------
Imagem: docs/manual/robo-rodas.webp
Peças deste passo:
  - 2× Roda 32 mm
O que fazer:
  * Aperte o parafuso da roda na parte plana do eixo. Gire com a mão: não pode raspar.
Quando terminar: passo 30 feito. Próximo: passo 31.

####################################################################################################
BLOCO 6 · BATERIA, CONECTOR E CHAVE · passos 31 a 37
####################################################################################################
A chave SS12D00 aguenta 0,5 A: liga só a eletrônica. Os motores recebem a bateria direto pelo fio 3.
Imagem de capa: docs/manual/chave-c5.webp

FIOS QUE ENTRAM NESTE BLOCO (corte e numere com fita nas duas pontas antes de começar)
  - Fio 1 — vermelho — 22 AWG — corte com 60 mm
      de: conector da bateria, fio + vermelho
      para: chave SS12D00, pino COM (o do meio)
  - Fio 2 — vermelho — 22 AWG — corte com 60 mm
      de: chave SS12D00, pino P1 (o do lado que LIGA, achado com o multímetro)
      para: LM2596, furo IN+
  - Fio 3 — vermelho — 22 AWG — corte com 120 mm
      de: conector da bateria, fio + vermelho
      para: ponte H TB6612, furo VM (fileira de energia, a do VM; 1º furo)
  - Fio 4 — preto — 22 AWG — corte com 120 mm
      de: conector da bateria, fio − preto
      para: ponte H TB6612, furo GND (fileira de energia, a do VM; 3º furo)
  - Fio 5 — preto — 22 AWG — corte com 50 mm
      de: conector da bateria, fio − preto
      para: LM2596, furo IN−

----------------------------------------------------------------------------------------------------
PASSO 31 de 69 · Bloco 6 · Bateria com velcro
----------------------------------------------------------------------------------------------------
Imagem: docs/manual/robo-bateria.webp
Peças deste passo:
  - 1× Bateria 7,4 V
  - 2 Tiras de velcro
O que fazer:
  * Velcro no piso e na bateria, deitada no fundo. Velcro e não cola: ela sai para carregar.
Quando terminar: passo 31 feito. Próximo: passo 32.

----------------------------------------------------------------------------------------------------
PASSO 32 de 69 · Bloco 6 · Descubra o lado que liga
----------------------------------------------------------------------------------------------------
Imagem: docs/manual/chave-c1.webp
Lupa (detalhe ampliado, no canto da imagem): docs/manual/chave-c1-lupa.webp
Na imagem: etiquetas “P1”, “COM”, “P2”, “+”, “−”.
Peças deste passo:
  - 1× Chave SS12D00 — 3 perninhas
  - 1× Conector — lado do robô
O que fazer:
  * O pino do meio é o COM. Bipe entre o COM e um pino do lado; empurre o botão: para um lado apita.
    Esse pino é o P1 e essa posição é LIGA.
Quando terminar: passo 32 feito. Próximo: passo 33.

----------------------------------------------------------------------------------------------------
PASSO 33 de 69 · Bloco 6 · Fio 1: conector + até o COM
----------------------------------------------------------------------------------------------------
Imagem: docs/manual/chave-c2.webp
Na imagem: círculo com o número do fio 1.
Peças deste passo:
  - Fio 1 — vermelho — 22 AWG — corte com 60 mm
  - Termorretrátil — pedaços de 1 a 2 cm
O que fazer:
  * Fio 1 no fio vermelho (+) do conector e a outra ponta no pino do meio da chave.
Ligações deste passo, fio a fio:
  - Fio 1:
      uma ponta: conector da bateria, fio + vermelho
      outra ponta: chave SS12D00, pino COM (o do meio)
      caminho: embaixo da plataforma
      observação: vermelho do conector da bateria, junto com o fio 3; na chave, pino do meio
ATENÇÃO: Solde com a bateria desconectada. Um toque do + no − derrete os fios.
Quando terminar: passo 33 feito. Próximo: passo 34.

----------------------------------------------------------------------------------------------------
PASSO 34 de 69 · Bloco 6 · Fio 2 no P1
----------------------------------------------------------------------------------------------------
Imagem: docs/manual/chave-c3.webp
Na imagem: círculo com o número do fio 2.
Peças deste passo:
  - Fio 2 — vermelho — 22 AWG — corte com 60 mm
  - Termorretrátil — pedaços de 1 a 2 cm
O que fazer:
  * Fio 2 no P1. Ele vai ao IN+ do LM2596. O terceiro pino fica vazio.
Ligações deste passo, fio a fio:
  - Fio 2: (também aparece no passo 39: uma ponta é soldada aqui e a outra lá)
      uma ponta: chave SS12D00, pino P1 (o do lado que LIGA, achado com o multímetro)
      outra ponta: LM2596, furo IN+
      caminho: embaixo da plataforma
      observação: na chave, o pino do lado que liga (confira com o multímetro)
Quando terminar: passo 34 feito. Próximo: passo 35.

----------------------------------------------------------------------------------------------------
PASSO 35 de 69 · Bloco 6 · Fio 3 no + do conector
----------------------------------------------------------------------------------------------------
Imagem: docs/manual/chave-c4.webp
Na imagem: círculo com o número do fio 3.
Peças deste passo:
  - Fio 3 — vermelho — 22 AWG — corte com 120 mm
O que fazer:
  * No mesmo ponto do fio 1, solde o fio 3. Ele vai direto ao VM da ponte H.
Ligações deste passo, fio a fio:
  - Fio 3: (também aparece no passo 57: uma ponta é soldada aqui e a outra lá)
      uma ponta: conector da bateria, fio + vermelho
      outra ponta: ponte H TB6612, furo VM (fileira de energia, a do VM; 1º furo)
      caminho: sobe pelo rasgo R4
      observação: vermelho do conector da bateria, junto com o fio 1: os motores não passam pela
        chave
CONFIRA: O + do conector fica com dois fios: 1 e 3.
Quando terminar: passo 35 feito. Próximo: passo 36.

----------------------------------------------------------------------------------------------------
PASSO 36 de 69 · Bloco 6 · Fios 4 e 5 no − do conector
----------------------------------------------------------------------------------------------------
Imagem: docs/manual/chave-c5.webp
Na imagem: círculos com os números dos fios 4, 5.
Peças deste passo:
  - Fio 4 — preto — 22 AWG — corte com 120 mm
  - Fio 5 — preto — 22 AWG — corte com 50 mm
  - Termorretrátil — pedaços de 1 a 2 cm
O que fazer:
  * No fio preto (−) do conector, solde juntos os fios 4 e 5. Termorretrátil nas duas emendas.
Ligações deste passo, fio a fio:
  - Fio 4: (também aparece no passo 59: uma ponta é soldada aqui e a outra lá)
      uma ponta: conector da bateria, fio − preto
      outra ponta: ponte H TB6612, furo GND (fileira de energia, a do VM; 3º furo)
      caminho: sobe pelo rasgo R4
      observação: preto do conector da bateria, junto com o fio 5
  - Fio 5: (também aparece no passo 39: uma ponta é soldada aqui e a outra lá)
      uma ponta: conector da bateria, fio − preto
      outra ponta: LM2596, furo IN−
      caminho: embaixo da plataforma
      observação: preto do conector da bateria, junto com o fio 4
CONFIRA: Bipe entre o + e o − do conector: não pode apitar.
Quando terminar: passo 36 feito. Próximo: passo 37.

----------------------------------------------------------------------------------------------------
PASSO 37 de 69 · Bloco 6 · Chave na lateral esquerda
----------------------------------------------------------------------------------------------------
Imagem: docs/manual/robo-chave.webp
Lupa (detalhe ampliado, no canto da imagem): docs/manual/robo-chave-lupa.webp
Peças deste passo:
  - Cola quente
O que fazer:
  * Cole a chave no furo retangular da lateral esquerda, botão para fora. O conector fica em cima da
    bateria.
Quando terminar: passo 37 feito. Próximo: passo 38.

####################################################################################################
BLOCO 7 · REGULADOR LM2596 · passos 38 a 41
####################################################################################################
Colado em cima da bateria. Transforma 7,4 V em 5 V e precisa ser ajustado antes de ligar a saída.
Imagem de capa: docs/manual/robo-lm-hc.webp

FIOS QUE ENTRAM NESTE BLOCO (corte e numere com fita nas duas pontas antes de começar)
  - Fio 10 — laranja — 26 AWG — corte com 130 mm
      de: LM2596, furo OUT+
      para: ESP32, pino VIN (fileira da FRENTE, a do EN…VIN, lado do sonar; 1º pino contando a partir da ponta do USB)
  - Fio 11 — preto — 26 AWG — corte com 120 mm
      de: LM2596, furo OUT−
      para: ESP32, pino GND (fileira da FRENTE, a do EN…VIN, lado do sonar; 2º pino contando a partir da ponta do USB)

----------------------------------------------------------------------------------------------------
PASSO 38 de 69 · Bloco 7 · Cole em cima da bateria
----------------------------------------------------------------------------------------------------
Imagem: docs/manual/robo-lm.webp
Peças deste passo:
  - 1× LM2596
  - Fita dupla-face
O que fazer:
  * Entrada (IN) para o lado esquerdo, perto da chave; saída (OUT) para o direito.
Quando terminar: passo 38 feito. Próximo: passo 39.

----------------------------------------------------------------------------------------------------
PASSO 39 de 69 · Bloco 7 · Fios 2 e 5 na entrada
----------------------------------------------------------------------------------------------------
Imagem: docs/manual/robo-lm-entrada.webp
Lupa (detalhe ampliado, no canto da imagem): docs/manual/robo-lm-entrada-lupa.webp
Peças deste passo:
  - Fio 2 — vermelho — 22 AWG — corte com 60 mm
  - Fio 5 — preto — 22 AWG — corte com 50 mm
O que fazer:
  * Fio 2 (da chave) no IN+. Fio 5 (do conector) no IN−. Leia o + e o − impressos.
Ligações deste passo, fio a fio:
  - Fio 2: (também aparece no passo 34: uma ponta é soldada aqui e a outra lá)
      uma ponta: chave SS12D00, pino P1 (o do lado que LIGA, achado com o multímetro)
      outra ponta: LM2596, furo IN+
      caminho: embaixo da plataforma
      observação: na chave, o pino do lado que liga (confira com o multímetro)
  - Fio 5: (também aparece no passo 36: uma ponta é soldada aqui e a outra lá)
      uma ponta: conector da bateria, fio − preto
      outra ponta: LM2596, furo IN−
      caminho: embaixo da plataforma
      observação: preto do conector da bateria, junto com o fio 4
ATENÇÃO: Entrada invertida queima o LM2596 na hora.
Quando terminar: passo 39 feito. Próximo: passo 40.

----------------------------------------------------------------------------------------------------
PASSO 40 de 69 · Bloco 7 · Ajuste para 5,00 V
----------------------------------------------------------------------------------------------------
Imagem: docs/manual/robo-lm-ajuste.webp
Peças deste passo:
  - Multímetro — tensão DC
  - Chave de fenda pequena
O que fazer:
  * Nada na saída. Bateria conectada, chave em LIGA. Vermelha no OUT+, preta no OUT−.
  * Gire o parafuso dourado: horário sobe. Pare em 5,00 V (pode levar 10 a 20 voltas). Depois
    desligue e desconecte a bateria.
ATENÇÃO: Ele vem de fábrica numa tensão qualquer, às vezes mais de 30 V. Ligar a saída antes de
    ajustar queima o sonar e o ESP32.
Quando terminar: passo 40 feito. Próximo: passo 41.

----------------------------------------------------------------------------------------------------
PASSO 41 de 69 · Bloco 7 · Fios 12, 10, 13 e 11 na saída
----------------------------------------------------------------------------------------------------
Imagem: docs/manual/robo-lm-hc.webp
Peças deste passo:
  - Fio 12 — laranja — 26 AWG — corte com 100 mm
  - Fio 10 — laranja — 26 AWG — corte com 130 mm
  - Fio 13 — preto — 26 AWG — corte com 100 mm
  - Fio 11 — preto — 26 AWG — corte com 120 mm
O que fazer:
  * No OUT+, juntos: 12 (sonar) e 10 (vai ao VIN do ESP32). No OUT−, juntos: 13 (sonar) e 11 (vai ao
    GND do ESP32).
Ligações deste passo, fio a fio:
  - Fio 12: (também aparece no passo 16: uma ponta é soldada aqui e a outra lá)
      uma ponta: LM2596, furo OUT+
      outra ponta: sonar HC-SR04, pino VCC
      caminho: embaixo da plataforma
      observação: divide o furo OUT+ com o fio 10
  - Fio 10: (também aparece no passo 54: uma ponta é soldada aqui e a outra lá)
      uma ponta: LM2596, furo OUT+
      outra ponta: ESP32, pino VIN (fileira da FRENTE, a do EN…VIN, lado do sonar; 1º pino contando
        a partir da ponta do USB)
      caminho: sobe por baixo da plataforma até a ponta do pino
      observação: divide o furo OUT+ com o fio 12
  - Fio 13: (também aparece no passo 16: uma ponta é soldada aqui e a outra lá)
      uma ponta: LM2596, furo OUT−
      outra ponta: sonar HC-SR04, pino GND
      caminho: embaixo da plataforma
      observação: divide o furo OUT− com o fio 11
  - Fio 11: (também aparece no passo 54: uma ponta é soldada aqui e a outra lá)
      uma ponta: LM2596, furo OUT−
      outra ponta: ESP32, pino GND (fileira da FRENTE, a do EN…VIN, lado do sonar; 2º pino contando
        a partir da ponta do USB)
      caminho: sobe por baixo da plataforma até a ponta do pino
      observação: divide o furo OUT− com o fio 13
CONFIRA: Cada furo da saída fica com dois fios.
Quando terminar: passo 41 feito. Próximo: passo 42.

####################################################################################################
BLOCO 8 · EMENDAS 3V3 E GND · passos 42 a 44
####################################################################################################
Um pino do ESP32 alimenta vários sensores porque o fio se divide numa emenda. São duas: 3V3 e GND.
Imagem de capa: docs/manual/robo-emendas.webp

FIOS QUE ENTRAM NESTE BLOCO (corte e numere com fita nas duas pontas antes de começar)
  - Fio 14 — amarelo — 26 AWG — corte com 110 mm
      de: ESP32, pino 3V3 (fileira de TRÁS, a do D23…3V3; 1º pino contando a partir da ponta do USB)
      para: emenda 3V3 (5 fios torcidos e soldados juntos)
  - Fio 15 — preto — 26 AWG — corte com 110 mm
      de: ESP32, pino GND (fileira de TRÁS, a do D23…3V3; 2º pino contando a partir da ponta do USB)
      para: emenda GND (5 fios torcidos e soldados juntos)
  - Fio 19 — amarelo — 26 AWG — corte com 130 mm
      de: emenda 3V3 (5 fios torcidos e soldados juntos)
      para: ponte H TB6612, furo VCC (fileira de energia, a do VM; 2º furo)

----------------------------------------------------------------------------------------------------
PASSO 42 de 69 · Bloco 8 · Emenda 3V3
----------------------------------------------------------------------------------------------------
Imagem: docs/manual/emendas-e1.webp
Na imagem: círculos com os números dos fios 14, 16, 17, 18, 19.
Peças deste passo:
  - Fio 14 — amarelo — 26 AWG — corte com 110 mm
  - Fio 16 — amarelo — 26 AWG — corte com 50 mm
  - Fio 17 — amarelo — 26 AWG — corte com 70 mm
  - Fio 18 — amarelo — 26 AWG — corte com 100 mm
  - Fio 19 — amarelo — 26 AWG — corte com 130 mm
  - Termorretrátil — pedaços de 1 a 2 cm
O que fazer:
  * Termorretrátil grosso num fio, desencape 5 mm de cada ponta, torça as cinco juntas e solde.
  * 16 e 17 (sensores), 18 (receptor), 19 (ponte H), 14 (3V3 do ESP32).
Ligações deste passo, fio a fio:
  - Fio 14: (também aparece no passo 55: uma ponta é soldada aqui e a outra lá)
      uma ponta: ESP32, pino 3V3 (fileira de TRÁS, a do D23…3V3; 1º pino contando a partir da ponta
        do USB)
      outra ponta: emenda 3V3 (5 fios torcidos e soldados juntos)
      caminho: sobe por baixo da plataforma até a ponta do pino
  - Fio 16: (também aparece no passo 9: uma ponta é soldada aqui e a outra lá)
      uma ponta: emenda 3V3 (5 fios torcidos e soldados juntos)
      outra ponta: ponta de cima dos dois resistores (100 Ω e 10 kΩ) do sensor esquerdo, torcidas
        juntas
      caminho: embaixo da plataforma
      observação: chega na junção dos dois resistores do TCRT esquerdo
  - Fio 17: (também aparece no passo 13: uma ponta é soldada aqui e a outra lá)
      uma ponta: emenda 3V3 (5 fios torcidos e soldados juntos)
      outra ponta: ponta de cima dos dois resistores (100 Ω e 10 kΩ) do sensor direito, torcidas
        juntas
      caminho: embaixo da plataforma
      observação: chega na junção dos dois resistores do TCRT direito
  - Fio 18: (também aparece no passo 24: uma ponta é soldada aqui e a outra lá)
      uma ponta: emenda 3V3 (5 fios torcidos e soldados juntos)
      outra ponta: receptor do juiz, perna VCC
      caminho: embaixo da plataforma
  - Fio 19: (também aparece no passo 58: uma ponta é soldada aqui e a outra lá)
      uma ponta: emenda 3V3 (5 fios torcidos e soldados juntos)
      outra ponta: ponte H TB6612, furo VCC (fileira de energia, a do VM; 2º furo)
      caminho: sobe pelo rasgo R2
ATENÇÃO: Só fios amarelos nesta emenda. Um preto aqui é curto direto no ESP32.
Quando terminar: passo 42 feito. Próximo: passo 43.

----------------------------------------------------------------------------------------------------
PASSO 43 de 69 · Bloco 8 · Emenda GND
----------------------------------------------------------------------------------------------------
Imagem: docs/manual/emendas-e2.webp
Na imagem: círculos com os números dos fios 15, 20, 21, 22, 26C.
Peças deste passo:
  - Fio 15 — preto — 26 AWG — corte com 110 mm
  - Fio 20 — preto — 26 AWG — corte com 80 mm
  - Fio 21 — preto — 26 AWG — corte com 50 mm
  - Fio 22 — preto — 26 AWG — corte com 70 mm
  - Fio 26C — preto — 26 AWG — corte com 40 mm
  - Termorretrátil — pedaços de 1 a 2 cm
O que fazer:
  * Cinco pretos: 20 e 21 (sensores), 22 (receptor), 26C (divisor do sonar), 15 (GND do ESP32).
Ligações deste passo, fio a fio:
  - Fio 15: (também aparece no passo 55: uma ponta é soldada aqui e a outra lá)
      uma ponta: ESP32, pino GND (fileira de TRÁS, a do D23…3V3; 2º pino contando a partir da ponta
        do USB)
      outra ponta: emenda GND (5 fios torcidos e soldados juntos)
      caminho: sobe por baixo da plataforma até a ponta do pino
  - Fio 20: (também aparece no passo 11: uma ponta é soldada aqui e a outra lá)
      uma ponta: emenda GND (5 fios torcidos e soldados juntos)
      outra ponta: sensor esquerdo (TCRT5000), perna K
      caminho: embaixo da plataforma
      observação: chega na ponte entre as pernas K e E
  - Fio 21: (também aparece no passo 13: uma ponta é soldada aqui e a outra lá)
      uma ponta: emenda GND (5 fios torcidos e soldados juntos)
      outra ponta: sensor direito (TCRT5000), perna K
      caminho: embaixo da plataforma
      observação: chega na ponte entre as pernas K e E
  - Fio 22: (também aparece no passo 24: uma ponta é soldada aqui e a outra lá)
      uma ponta: emenda GND (5 fios torcidos e soldados juntos)
      outra ponta: receptor do juiz, perna GND
      caminho: embaixo da plataforma
  - Fio 26C: (também aparece no passo 20: uma ponta é soldada aqui e a outra lá)
      uma ponta: resistor 2 kΩ do divisor do sonar (perna livre, onde vai o fio 26C)
      outra ponta: emenda GND (5 fios torcidos e soldados juntos)
      caminho: embaixo da plataforma
      observação: do 2 kΩ até a emenda GND
CONFIRA: O GND do sonar e o da ponte H não entram aqui.
Quando terminar: passo 43 feito. Próximo: passo 44.

----------------------------------------------------------------------------------------------------
PASSO 44 de 69 · Bloco 8 · Encolha e acomode
----------------------------------------------------------------------------------------------------
Imagem: docs/manual/robo-emendas.webp
O que fazer:
  * Aqueça os tubos e acomode as emendas atrás do sonar, em cima da borda da placa dele.
CONFIRA: Bipe entre um fio da emenda 3V3 e um da GND: não pode apitar.
Quando terminar: passo 44 feito. Próximo: passo 45.

####################################################################################################
BLOCO 9 · PLATAFORMA: ESP32 E PONTE H · passos 45 a 52
####################################################################################################
Na bancada, fora do robô. O ESP32 fica apoiado na plataforma com os pinos atravessando os rasgos, e
todo fio do ESP32 é soldado na ponta do pino, por baixo.
Imagem de capa: docs/manual/robo-plat-tb.webp

FIOS QUE ENTRAM NESTE BLOCO (corte e numere com fita nas duas pontas antes de começar)
  - Fio 28 — marrom — 26 AWG — corte com 110 mm
      de: ponte H TB6612, furo PWMA (fileira de controle, a do PWMA; 1º furo)
      para: ESP32, pino D25 (fileira da FRENTE, a do EN…VIN, lado do sonar; 8º pino contando a partir da ponta do USB)
  - Fio 29 — azul — 26 AWG — corte com 100 mm
      de: ponte H TB6612, furo AIN2 (fileira de controle, a do PWMA; 2º furo)
      para: ESP32, pino D27 (fileira da FRENTE, a do EN…VIN, lado do sonar; 6º pino contando a partir da ponta do USB)
  - Fio 30 — verde — 26 AWG — corte com 100 mm
      de: ponte H TB6612, furo AIN1 (fileira de controle, a do PWMA; 3º furo)
      para: ESP32, pino D26 (fileira da FRENTE, a do EN…VIN, lado do sonar; 7º pino contando a partir da ponta do USB)
  - Fio 31 — roxo — 26 AWG — corte com 90 mm
      de: ponte H TB6612, furo STBY (fileira de controle, a do PWMA; 4º furo)
      para: ESP32, pino D13 (fileira da FRENTE, a do EN…VIN, lado do sonar; 3º pino contando a partir da ponta do USB)
  - Fio 32 — verde — 26 AWG — corte com 100 mm
      de: ponte H TB6612, furo BIN1 (fileira de controle, a do PWMA; 5º furo)
      para: ESP32, pino D32 (fileira da FRENTE, a do EN…VIN, lado do sonar; 10º pino contando a partir da ponta do USB)
  - Fio 33 — azul — 26 AWG — corte com 100 mm
      de: ponte H TB6612, furo BIN2 (fileira de controle, a do PWMA; 6º furo)
      para: ESP32, pino D33 (fileira da FRENTE, a do EN…VIN, lado do sonar; 9º pino contando a partir da ponta do USB)
  - Fio 34 — marrom — 26 AWG — corte com 80 mm
      de: ponte H TB6612, furo PWMB (fileira de controle, a do PWMA; 7º furo)
      para: ESP32, pino D14 (fileira da FRENTE, a do EN…VIN, lado do sonar; 5º pino contando a partir da ponta do USB)

----------------------------------------------------------------------------------------------------
PASSO 45 de 69 · Bloco 9 · Grave o código antes de soldar
----------------------------------------------------------------------------------------------------
Imagem: nenhuma (passo só de texto)
Peças deste passo:
  - 1× Cabo USB de dados
O que fazer:
  * Com o ESP32 solto, ligue no computador e grave o código com MODO_TESTE = true (passo a passo no
    bloco 13).
  * Depois de montado, o USB fica encostado na ponte H e o cabo pode não entrar.
CONFIRA: O LED azul da placa pisca depois de gravar.
Quando terminar: passo 45 feito. Próximo: passo 46.

----------------------------------------------------------------------------------------------------
PASSO 46 de 69 · Bloco 9 · Os dois rasgos do ESP32
----------------------------------------------------------------------------------------------------
Imagem: docs/manual/robo-plat-rasgos.webp
Lupa (detalhe ampliado, no canto da imagem): docs/manual/robo-plat-rasgos-lupa.webp
O que fazer:
  * Corte dois rasgos de 40 × 2 mm, um embaixo de cada fileira de pinos, com 25,4 mm entre os
    centros. Apoie o ESP32 no lugar e risque com caneta onde os pinos encostam.
CONFIRA: A plataforma continua com as 4 janelas grandes e pequenas: R1 e R2 na frente, R3 e R4
    atrás.
Quando terminar: passo 46 feito. Próximo: passo 47.

----------------------------------------------------------------------------------------------------
PASSO 47 de 69 · Bloco 9 · Encaixe o ESP32 e cole
----------------------------------------------------------------------------------------------------
Imagem: docs/manual/robo-plat-esp.webp
Lupa (detalhe ampliado, no canto da imagem): docs/manual/robo-plat-esp-lupa.webp
Peças deste passo:
  - 1× ESP32 DevKit V1 — 30 pinos, com a barra de pinos
  - Cola quente
O que fazer:
  * USB para a esquerda do robô, virado para onde vai a ponte H. A fileira com EN e VIN fica na
    frente, do lado do sonar.
  * Um ponto de cola quente em cada ponta das duas barras pretas.
ATENÇÃO: Antes de virar a plataforma, pinte com caneta, por baixo, a ponta do pino VIN e a do 3V3.
    Por baixo não aparece nenhum nome.
Quando terminar: passo 47 feito. Próximo: passo 48.

----------------------------------------------------------------------------------------------------
PASSO 48 de 69 · Bloco 9 · Ponte H: fios 28 a 31
----------------------------------------------------------------------------------------------------
Imagem: docs/manual/ponteh-g6.webp
Lupa (detalhe ampliado, no canto da imagem): docs/manual/ponteh-g6-lupa.webp
Na imagem: círculos com os números dos fios 28, 29, 30, 31.
Peças deste passo:
  - Fio 28 — marrom — 26 AWG — corte com 110 mm
  - Fio 29 — azul — 26 AWG — corte com 100 mm
  - Fio 30 — verde — 26 AWG — corte com 100 mm
  - Fio 31 — roxo — 26 AWG — corte com 90 mm
O que fazer:
  * Com a placa na mão. Fileira de controle: 28 PWMA, 29 AIN2, 30 AIN1, 31 STBY.
Ligações deste passo, fio a fio:
  - Fio 28: (também aparece no passo 52: uma ponta é soldada aqui e a outra lá)
      uma ponta: ponte H TB6612, furo PWMA (fileira de controle, a do PWMA; 1º furo)
      outra ponta: ESP32, pino D25 (fileira da FRENTE, a do EN…VIN, lado do sonar; 8º pino contando
        a partir da ponta do USB)
      caminho: desce pelo rasgo R2 e sobe por baixo até a ponta do pino
  - Fio 29: (também aparece no passo 52: uma ponta é soldada aqui e a outra lá)
      uma ponta: ponte H TB6612, furo AIN2 (fileira de controle, a do PWMA; 2º furo)
      outra ponta: ESP32, pino D27 (fileira da FRENTE, a do EN…VIN, lado do sonar; 6º pino contando
        a partir da ponta do USB)
      caminho: desce pelo rasgo R2 e sobe por baixo até a ponta do pino
  - Fio 30: (também aparece no passo 52: uma ponta é soldada aqui e a outra lá)
      uma ponta: ponte H TB6612, furo AIN1 (fileira de controle, a do PWMA; 3º furo)
      outra ponta: ESP32, pino D26 (fileira da FRENTE, a do EN…VIN, lado do sonar; 7º pino contando
        a partir da ponta do USB)
      caminho: desce pelo rasgo R2 e sobe por baixo até a ponta do pino
  - Fio 31: (também aparece no passo 52: uma ponta é soldada aqui e a outra lá)
      uma ponta: ponte H TB6612, furo STBY (fileira de controle, a do PWMA; 4º furo)
      outra ponta: ESP32, pino D13 (fileira da FRENTE, a do EN…VIN, lado do sonar; 3º pino contando
        a partir da ponta do USB)
      caminho: desce pelo rasgo R2 e sobe por baixo até a ponta do pino
Quando terminar: passo 48 feito. Próximo: passo 49.

----------------------------------------------------------------------------------------------------
PASSO 49 de 69 · Bloco 9 · Ponte H: fios 32 a 34
----------------------------------------------------------------------------------------------------
Imagem: docs/manual/ponteh-g7.webp
Lupa (detalhe ampliado, no canto da imagem): docs/manual/ponteh-g7-lupa.webp
Na imagem: círculos com os números dos fios 32, 33, 34.
Peças deste passo:
  - Fio 32 — verde — 26 AWG — corte com 100 mm
  - Fio 33 — azul — 26 AWG — corte com 100 mm
  - Fio 34 — marrom — 26 AWG — corte com 80 mm
O que fazer:
  * 32 BIN1, 33 BIN2, 34 PWMB. O último GND fica vazio.
Ligações deste passo, fio a fio:
  - Fio 32: (também aparece no passo 52: uma ponta é soldada aqui e a outra lá)
      uma ponta: ponte H TB6612, furo BIN1 (fileira de controle, a do PWMA; 5º furo)
      outra ponta: ESP32, pino D32 (fileira da FRENTE, a do EN…VIN, lado do sonar; 10º pino contando
        a partir da ponta do USB)
      caminho: desce pelo rasgo R2 e sobe por baixo até a ponta do pino
      observação: fita “B”
  - Fio 33: (também aparece no passo 52: uma ponta é soldada aqui e a outra lá)
      uma ponta: ponte H TB6612, furo BIN2 (fileira de controle, a do PWMA; 6º furo)
      outra ponta: ESP32, pino D33 (fileira da FRENTE, a do EN…VIN, lado do sonar; 9º pino contando
        a partir da ponta do USB)
      caminho: desce pelo rasgo R2 e sobe por baixo até a ponta do pino
      observação: fita “B”
  - Fio 34: (também aparece no passo 52: uma ponta é soldada aqui e a outra lá)
      uma ponta: ponte H TB6612, furo PWMB (fileira de controle, a do PWMA; 7º furo)
      outra ponta: ESP32, pino D14 (fileira da FRENTE, a do EN…VIN, lado do sonar; 5º pino contando
        a partir da ponta do USB)
      caminho: desce pelo rasgo R2 e sobe por baixo até a ponta do pino
      observação: fita “B”
Quando terminar: passo 49 feito. Próximo: passo 50.

----------------------------------------------------------------------------------------------------
PASSO 50 de 69 · Bloco 9 · Cole a ponte H e desça os 7 fios
----------------------------------------------------------------------------------------------------
Imagem: docs/manual/robo-plat-tb.webp
Lupa (detalhe ampliado, no canto da imagem): docs/manual/robo-plat-tb-lupa.webp
Peças deste passo:
  - Fita dupla-face
O que fazer:
  * Ao lado da ponta USB do ESP32, com a fileira de controle virada para ele. Passe os 7 fios juntos
    pelo rasgo R2, o pequeno da frente, de cima para baixo.
Quando terminar: passo 50 feito. Próximo: passo 51.

----------------------------------------------------------------------------------------------------
PASSO 51 de 69 · Bloco 9 · Como soldar na ponta do pino
----------------------------------------------------------------------------------------------------
Imagem: docs/manual/esp-pino.webp
Lupa (detalhe ampliado, no canto da imagem): docs/manual/esp-pino-lupa.webp
Na imagem: etiquetas “1”, “2”, “3”, “4”.
Peças deste passo:
  - Termorretrátil fino — 1,5 mm, um pedaço de 6 mm por pino
O que fazer:
  * Plataforma de cabeça para baixo: os pinos saem uns 3 mm pelo rasgo.
  * 1 Desencape 3 mm, estanhe e passe o termorretrátil longe da ponta. 2 Encoste o fio em pé, colado
    no pino. 3 Solde com 2 segundos de ferro. 4 Desça o tubo até a plataforma e aqueça.
ATENÇÃO: Os pinos ficam a 2,54 mm um do outro. Sem termorretrátil, um fio encosta no vizinho.
Quando terminar: passo 51 feito. Próximo: passo 52.

----------------------------------------------------------------------------------------------------
PASSO 52 de 69 · Bloco 9 · Fios 28 a 34 nos pinos, por baixo
----------------------------------------------------------------------------------------------------
Imagem: docs/manual/robo-plat-controle.webp
Lupa (detalhe ampliado, no canto da imagem): docs/manual/robo-plat-controle-lupa.webp
Na imagem: círculos com os números dos fios 28, 29, 30, 31, 32, 33, 34.
Peças deste passo:
  - Fio 28 — marrom — 26 AWG — corte com 110 mm
  - Fio 29 — azul — 26 AWG — corte com 100 mm
  - Fio 30 — verde — 26 AWG — corte com 100 mm
  - Fio 31 — roxo — 26 AWG — corte com 90 mm
  - Fio 32 — verde — 26 AWG — corte com 100 mm
  - Fio 33 — azul — 26 AWG — corte com 100 mm
  - Fio 34 — marrom — 26 AWG — corte com 80 mm
  - Termorretrátil fino — 1,5 mm, um pedaço de 6 mm por pino
O que fazer:
  * Fileira da frente (a do VIN). Conte a partir do pino pintado.
Tabela:
    Pino, contando do USB | Nome na placa | Fio
    ----------------------+---------------+------
    3º                    | D13           | 31
    4º                    | D12           | vazio
    5º                    | D14           | 34
    6º                    | D27           | 29
    7º                    | D26           | 30
    8º                    | D25           | 28
    9º                    | D33           | 33
    10º                   | D32           | 32
Ligações deste passo, fio a fio:
  - Fio 28: (também aparece no passo 48: uma ponta é soldada aqui e a outra lá)
      uma ponta: ponte H TB6612, furo PWMA (fileira de controle, a do PWMA; 1º furo)
      outra ponta: ESP32, pino D25 (fileira da FRENTE, a do EN…VIN, lado do sonar; 8º pino contando
        a partir da ponta do USB)
      caminho: desce pelo rasgo R2 e sobe por baixo até a ponta do pino
  - Fio 29: (também aparece no passo 48: uma ponta é soldada aqui e a outra lá)
      uma ponta: ponte H TB6612, furo AIN2 (fileira de controle, a do PWMA; 2º furo)
      outra ponta: ESP32, pino D27 (fileira da FRENTE, a do EN…VIN, lado do sonar; 6º pino contando
        a partir da ponta do USB)
      caminho: desce pelo rasgo R2 e sobe por baixo até a ponta do pino
  - Fio 30: (também aparece no passo 48: uma ponta é soldada aqui e a outra lá)
      uma ponta: ponte H TB6612, furo AIN1 (fileira de controle, a do PWMA; 3º furo)
      outra ponta: ESP32, pino D26 (fileira da FRENTE, a do EN…VIN, lado do sonar; 7º pino contando
        a partir da ponta do USB)
      caminho: desce pelo rasgo R2 e sobe por baixo até a ponta do pino
  - Fio 31: (também aparece no passo 48: uma ponta é soldada aqui e a outra lá)
      uma ponta: ponte H TB6612, furo STBY (fileira de controle, a do PWMA; 4º furo)
      outra ponta: ESP32, pino D13 (fileira da FRENTE, a do EN…VIN, lado do sonar; 3º pino contando
        a partir da ponta do USB)
      caminho: desce pelo rasgo R2 e sobe por baixo até a ponta do pino
  - Fio 32: (também aparece no passo 49: uma ponta é soldada aqui e a outra lá)
      uma ponta: ponte H TB6612, furo BIN1 (fileira de controle, a do PWMA; 5º furo)
      outra ponta: ESP32, pino D32 (fileira da FRENTE, a do EN…VIN, lado do sonar; 10º pino contando
        a partir da ponta do USB)
      caminho: desce pelo rasgo R2 e sobe por baixo até a ponta do pino
      observação: fita “B”
  - Fio 33: (também aparece no passo 49: uma ponta é soldada aqui e a outra lá)
      uma ponta: ponte H TB6612, furo BIN2 (fileira de controle, a do PWMA; 6º furo)
      outra ponta: ESP32, pino D33 (fileira da FRENTE, a do EN…VIN, lado do sonar; 9º pino contando
        a partir da ponta do USB)
      caminho: desce pelo rasgo R2 e sobe por baixo até a ponta do pino
      observação: fita “B”
  - Fio 34: (também aparece no passo 49: uma ponta é soldada aqui e a outra lá)
      uma ponta: ponte H TB6612, furo PWMB (fileira de controle, a do PWMA; 7º furo)
      outra ponta: ESP32, pino D14 (fileira da FRENTE, a do EN…VIN, lado do sonar; 5º pino contando
        a partir da ponta do USB)
      caminho: desce pelo rasgo R2 e sobe por baixo até a ponta do pino
      observação: fita “B”
CONFIRA: Bipe entre cada furo da ponte H e o pino dele no ESP32: tem que apitar. Bipe entre cada
    pino soldado e o pino do lado: não pode apitar.
Quando terminar: passo 52 feito. Próximo: passo 53.

####################################################################################################
BLOCO 10 · PLATAFORMA NO ROBÔ · passos 53 a 56
####################################################################################################
Os fios que vêm de baixo sobem direto até a ponta dos pinos do ESP32. Solde com a plataforma de
cabeça para baixo, apoiada na frente do robô.
Imagem de capa: docs/manual/robo-plataforma.webp

----------------------------------------------------------------------------------------------------
PASSO 53 de 69 · Bloco 10 · Espaçadores: 12 mm + 5 mm
----------------------------------------------------------------------------------------------------
Imagem: docs/manual/robo-espacadores.webp
Peças deste passo:
  - 4× Espaçador de 12 mm
  - 4× Espaçador de 5 mm
O que fazer:
  * Em cada uma das 4 colunas do chassi: um espaçador de 12 mm e um de 5 mm por cima. A plataforma
    sobe 17 mm.
CONFIRA: Se, com a plataforma no lugar, algum fio encostar com força no LM2596, troque o de 5 mm por
    um de 12 mm.
Quando terminar: passo 53 feito. Próximo: passo 54.

----------------------------------------------------------------------------------------------------
PASSO 54 de 69 · Bloco 10 · Fileira da frente: 10, 11, 23 e 24
----------------------------------------------------------------------------------------------------
Imagem: docs/manual/robo-esp-frente.webp
Lupa (detalhe ampliado, no canto da imagem): docs/manual/robo-esp-frente-lupa.webp
Na imagem: círculos com os números dos fios 10, 11, 23, 24.
Peças deste passo:
  - Fio 10 — laranja — 26 AWG — corte com 130 mm
  - Fio 11 — preto — 26 AWG — corte com 120 mm
  - Fio 23 — branco — 26 AWG — corte com 150 mm
  - Fio 24 — cinza — 26 AWG — corte com 110 mm
  - Termorretrátil fino — 1,5 mm, um pedaço de 6 mm por pino
O que fazer:
  * A fileira do VIN, do lado do sonar. Cada fio sobe reto por baixo e é soldado na ponta do pino.
Tabela:
    Pino, contando do USB | Nome na placa | Fio
    ----------------------+---------------+----
    1º                    | VIN           | 10
    2º                    | GND           | 11
    11º                   | D35           | 24
    12º                   | D34           | 23
Ligações deste passo, fio a fio:
  - Fio 10: (também aparece no passo 41: uma ponta é soldada aqui e a outra lá)
      uma ponta: LM2596, furo OUT+
      outra ponta: ESP32, pino VIN (fileira da FRENTE, a do EN…VIN, lado do sonar; 1º pino contando
        a partir da ponta do USB)
      caminho: sobe por baixo da plataforma até a ponta do pino
      observação: divide o furo OUT+ com o fio 12
  - Fio 11: (também aparece no passo 41: uma ponta é soldada aqui e a outra lá)
      uma ponta: LM2596, furo OUT−
      outra ponta: ESP32, pino GND (fileira da FRENTE, a do EN…VIN, lado do sonar; 2º pino contando
        a partir da ponta do USB)
      caminho: sobe por baixo da plataforma até a ponta do pino
      observação: divide o furo OUT− com o fio 13
  - Fio 23: (também aparece no passo 10: uma ponta é soldada aqui e a outra lá)
      uma ponta: sensor esquerdo (TCRT5000), perna C
      outra ponta: ESP32, pino D34 (fileira da FRENTE, a do EN…VIN, lado do sonar; 12º pino contando
        a partir da ponta do USB)
      caminho: sobe por baixo da plataforma até a ponta do pino
      observação: junto com o 10 kΩ na perna C
  - Fio 24: (também aparece no passo 13: uma ponta é soldada aqui e a outra lá)
      uma ponta: sensor direito (TCRT5000), perna C
      outra ponta: ESP32, pino D35 (fileira da FRENTE, a do EN…VIN, lado do sonar; 11º pino contando
        a partir da ponta do USB)
      caminho: sobe por baixo da plataforma até a ponta do pino
      observação: junto com o 10 kΩ na perna C
ATENÇÃO: VIN é o 1º da fileira da frente e 3V3 é o 1º da de trás. O fio 10 (5 V) no 3V3 queima o
    ESP32 e todos os sensores.
Quando terminar: passo 54 feito. Próximo: passo 55.

----------------------------------------------------------------------------------------------------
PASSO 55 de 69 · Bloco 10 · Fileira de trás: 14, 15, 25, 26B e 27
----------------------------------------------------------------------------------------------------
Imagem: docs/manual/robo-esp-tras.webp
Lupa (detalhe ampliado, no canto da imagem): docs/manual/robo-esp-tras-lupa.webp
Na imagem: círculos com os números dos fios 14, 15, 25, 26B, 27.
Peças deste passo:
  - Fio 14 — amarelo — 26 AWG — corte com 110 mm
  - Fio 15 — preto — 26 AWG — corte com 110 mm
  - Fio 25 — verde — 26 AWG — corte com 150 mm
  - Fio 26B — azul — 26 AWG — corte com 110 mm
  - Fio 27 — roxo — 26 AWG — corte com 130 mm
  - Termorretrátil fino — 1,5 mm, um pedaço de 6 mm por pino
O que fazer:
  * A fileira do 3V3. Os fios passam por cima do LM2596 e sobem até o pino.
Tabela:
    Pino, contando do USB | Nome na placa | Fio
    ----------------------+---------------+----
    1º                    | 3V3           | 14
    2º                    | GND           | 15
    8º                    | D5            | 25
    9º                    | D18           | 26B
    10º                   | D19           | 27
Ligações deste passo, fio a fio:
  - Fio 14: (também aparece no passo 42: uma ponta é soldada aqui e a outra lá)
      uma ponta: ESP32, pino 3V3 (fileira de TRÁS, a do D23…3V3; 1º pino contando a partir da ponta
        do USB)
      outra ponta: emenda 3V3 (5 fios torcidos e soldados juntos)
      caminho: sobe por baixo da plataforma até a ponta do pino
  - Fio 15: (também aparece no passo 43: uma ponta é soldada aqui e a outra lá)
      uma ponta: ESP32, pino GND (fileira de TRÁS, a do D23…3V3; 2º pino contando a partir da ponta
        do USB)
      outra ponta: emenda GND (5 fios torcidos e soldados juntos)
      caminho: sobe por baixo da plataforma até a ponta do pino
  - Fio 25: (também aparece no passo 17: uma ponta é soldada aqui e a outra lá)
      uma ponta: sonar HC-SR04, pino TRIG
      outra ponta: ESP32, pino D5 (fileira de TRÁS, a do D23…3V3; 8º pino contando a partir da ponta
        do USB)
      caminho: sobe por baixo da plataforma até a ponta do pino
  - Fio 26B: (também aparece no passo 19: uma ponta é soldada aqui e a outra lá)
      uma ponta: nó do divisor do sonar (perna do 1 kΩ onde também estão o 2 kΩ e o fio 26B)
      outra ponta: ESP32, pino D18 (fileira de TRÁS, a do D23…3V3; 9º pino contando a partir da
        ponta do USB)
      caminho: sobe por baixo da plataforma até a ponta do pino
      observação: sai do nó do divisor (já 3,3 V)
  - Fio 27: (também aparece no passo 24: uma ponta é soldada aqui e a outra lá)
      uma ponta: receptor do juiz, perna OUT
      outra ponta: ESP32, pino D19 (fileira de TRÁS, a do D23…3V3; 10º pino contando a partir da
        ponta do USB)
      caminho: sobe por baixo da plataforma até a ponta do pino
CONFIRA: Bipe entre VIN e 3V3: não pode apitar. Bipe entre cada pino soldado e o pino do lado: não
    pode apitar.
Quando terminar: passo 55 feito. Próximo: passo 56.

----------------------------------------------------------------------------------------------------
PASSO 56 de 69 · Bloco 10 · Apoie a plataforma
----------------------------------------------------------------------------------------------------
Imagem: docs/manual/robo-plataforma.webp
O que fazer:
  * Vire a plataforma para cima, passe os fios da ponte H pelos rasgos de baixo para cima e apoie
    nos espaçadores. Ainda sem parafuso.
Tabela:
    Rasgo                | Fios
    ---------------------+------------------------------------
    R2 · pequeno, frente | 19 sobe · 28 a 34 já descem por ele
    R4 · pequeno, trás   | 3, 4, 6, 7, 8 e 9 sobem
    R1 e R3 · grandes    | nenhum fio
Quando terminar: passo 56 feito. Próximo: passo 57.

####################################################################################################
BLOCO 11 · PONTE H: ENERGIA E MOTORES · passos 57 a 62
####################################################################################################
A ponte H já está colada na plataforma. As imagens mostram a placa solta só para ler o nome de cada
furo.
Imagem de capa: docs/manual/robo-tb.webp

----------------------------------------------------------------------------------------------------
PASSO 57 de 69 · Bloco 11 · Fio 3 no VM
----------------------------------------------------------------------------------------------------
Imagem: docs/manual/ponteh-g1.webp
Lupa (detalhe ampliado, no canto da imagem): docs/manual/ponteh-g1-lupa.webp
Na imagem: círculo com o número do fio 3.
Peças deste passo:
  - Fio 3 — vermelho — 22 AWG — corte com 120 mm
O que fazer:
  * Fileira de energia, primeiro furo: VM, os 7,4 V dos motores.
Ligações deste passo, fio a fio:
  - Fio 3: (também aparece no passo 35: uma ponta é soldada aqui e a outra lá)
      uma ponta: conector da bateria, fio + vermelho
      outra ponta: ponte H TB6612, furo VM (fileira de energia, a do VM; 1º furo)
      caminho: sobe pelo rasgo R4
      observação: vermelho do conector da bateria, junto com o fio 1: os motores não passam pela
        chave
ATENÇÃO: O VM fica colado no VCC. 7,4 V no VCC queima a ponte H, o ESP32 e os sensores.
Quando terminar: passo 57 feito. Próximo: passo 58.

----------------------------------------------------------------------------------------------------
PASSO 58 de 69 · Bloco 11 · Fio 19 no VCC
----------------------------------------------------------------------------------------------------
Imagem: docs/manual/ponteh-g2.webp
Lupa (detalhe ampliado, no canto da imagem): docs/manual/ponteh-g2-lupa.webp
Na imagem: círculo com o número do fio 19.
Peças deste passo:
  - Fio 19 — amarelo — 26 AWG — corte com 130 mm
O que fazer:
  * Segundo furo: VCC. O fio 19 vem da emenda 3V3 e sobe pelo rasgo R2.
Ligações deste passo, fio a fio:
  - Fio 19: (também aparece no passo 42: uma ponta é soldada aqui e a outra lá)
      uma ponta: emenda 3V3 (5 fios torcidos e soldados juntos)
      outra ponta: ponte H TB6612, furo VCC (fileira de energia, a do VM; 2º furo)
      caminho: sobe pelo rasgo R2
Quando terminar: passo 58 feito. Próximo: passo 59.

----------------------------------------------------------------------------------------------------
PASSO 59 de 69 · Bloco 11 · Fio 4 no GND
----------------------------------------------------------------------------------------------------
Imagem: docs/manual/ponteh-g3.webp
Lupa (detalhe ampliado, no canto da imagem): docs/manual/ponteh-g3-lupa.webp
Na imagem: círculo com o número do fio 4.
Peças deste passo:
  - Fio 4 — preto — 22 AWG — corte com 120 mm
O que fazer:
  * Terceiro furo: GND. O último GND da fileira fica vazio.
Ligações deste passo, fio a fio:
  - Fio 4: (também aparece no passo 36: uma ponta é soldada aqui e a outra lá)
      uma ponta: conector da bateria, fio − preto
      outra ponta: ponte H TB6612, furo GND (fileira de energia, a do VM; 3º furo)
      caminho: sobe pelo rasgo R4
      observação: preto do conector da bateria, junto com o fio 5
Quando terminar: passo 59 feito. Próximo: passo 60.

----------------------------------------------------------------------------------------------------
PASSO 60 de 69 · Bloco 11 · Motor esquerdo: 6 e 7
----------------------------------------------------------------------------------------------------
Imagem: docs/manual/ponteh-g4.webp
Lupa (detalhe ampliado, no canto da imagem): docs/manual/ponteh-g4-lupa.webp
Na imagem: círculos com os números dos fios 6, 7.
Peças deste passo:
  - Fio 6 — cinza — 22 AWG — corte com 160 mm
  - Fio 7 — cinza — 22 AWG — corte com 160 mm
O que fazer:
  * 6 no A01 e 7 no A02.
Ligações deste passo, fio a fio:
  - Fio 6: (também aparece no passo 26: uma ponta é soldada aqui e a outra lá)
      uma ponta: motor esquerdo, um dos dois terminais
      outra ponta: ponte H TB6612, furo A01 (fileira de energia, a do VM; 4º furo)
      caminho: furo Ø6 da tampa e rasgo R4
  - Fio 7: (também aparece no passo 26: uma ponta é soldada aqui e a outra lá)
      uma ponta: motor esquerdo, um dos dois terminais
      outra ponta: ponte H TB6612, furo A02 (fileira de energia, a do VM; 5º furo)
      caminho: furo Ø6 da tampa e rasgo R4
Quando terminar: passo 60 feito. Próximo: passo 61.

----------------------------------------------------------------------------------------------------
PASSO 61 de 69 · Bloco 11 · Motor direito: 9 e 8
----------------------------------------------------------------------------------------------------
Imagem: docs/manual/ponteh-g5.webp
Lupa (detalhe ampliado, no canto da imagem): docs/manual/ponteh-g5-lupa.webp
Na imagem: círculos com os números dos fios 9, 8.
Peças deste passo:
  - Fio 9 — branco — 22 AWG — corte com 160 mm
  - Fio 8 — branco — 22 AWG — corte com 160 mm
O que fazer:
  * 9 no B02 e 8 no B01. Na placa o B02 vem antes.
Ligações deste passo, fio a fio:
  - Fio 9: (também aparece no passo 26: uma ponta é soldada aqui e a outra lá)
      uma ponta: motor direito, um dos dois terminais
      outra ponta: ponte H TB6612, furo B02 (fileira de energia, a do VM; 6º furo)
      caminho: furo Ø6 da tampa e rasgo R4
  - Fio 8: (também aparece no passo 26: uma ponta é soldada aqui e a outra lá)
      uma ponta: motor direito, um dos dois terminais
      outra ponta: ponte H TB6612, furo B01 (fileira de energia, a do VM; 7º furo)
      caminho: furo Ø6 da tampa e rasgo R4
CONFIRA: Bipe entre VM e VCC e entre VM e GND: não pode apitar.
Quando terminar: passo 61 feito. Próximo: passo 62.

----------------------------------------------------------------------------------------------------
PASSO 62 de 69 · Bloco 11 · Confira a ponte H no robô
----------------------------------------------------------------------------------------------------
Imagem: docs/manual/robo-tb.webp
Lupa (detalhe ampliado, no canto da imagem): docs/manual/robo-tb-lupa.webp
O que fazer:
  * Sete fios na fileira de energia e sete na de controle. Nenhum fio esticado: a plataforma ainda
    vai receber o capô.
Quando terminar: passo 62 feito. Próximo: passo 63.

####################################################################################################
BLOCO 12 · CONFERIR E FECHAR · passos 63 a 66
####################################################################################################
Dez minutos de multímetro evitam queimar a placa. Com o capô fechado não dá mais para consertar.
Imagem de capa: docs/manual/robo-capo.webp

----------------------------------------------------------------------------------------------------
PASSO 63 de 69 · Bloco 12 · O que NÃO pode apitar
----------------------------------------------------------------------------------------------------
Imagem: nenhuma (passo só de texto)
Peças deste passo:
  - Multímetro — no bipe
O que fazer:
  * Bateria desconectada.
Tabela:
    Ponta vermelha             | Ponta preta    | Resultado
    ---------------------------+----------------+----------------
    + do conector              | − do conector  | não pode apitar
    VM da ponte H              | VCC da ponte H | não pode apitar
    VIN do ESP32               | 3V3 do ESP32   | não pode apitar
    3V3 do ESP32               | GND do ESP32   | não pode apitar
    cada pino soldado do ESP32 | o pino do lado | não pode apitar
    IN+ do LM2596, chave LIGA  | IN− do LM2596  | não pode apitar
ATENÇÃO: Se algum apitar, há curto. Não ligue a bateria.
Quando terminar: passo 63 feito. Próximo: passo 64.

----------------------------------------------------------------------------------------------------
PASSO 64 de 69 · Bloco 12 · O que TEM que apitar
----------------------------------------------------------------------------------------------------
Imagem: nenhuma (passo só de texto)
O que fazer:
  * Ainda sem bateria.
Tabela:
    Ponta vermelha | Ponta preta    | Resultado
    ---------------+----------------+---------------
    − do conector  | GND do ESP32   | tem que apitar
    − do conector  | GND da ponte H | tem que apitar
    OUT+ do LM2596 | VIN do ESP32   | tem que apitar
    + do conector  | VM da ponte H  | tem que apitar
Quando terminar: passo 64 feito. Próximo: passo 65.

----------------------------------------------------------------------------------------------------
PASSO 65 de 69 · Bloco 12 · Primeira vez ligado
----------------------------------------------------------------------------------------------------
Imagem: nenhuma (passo só de texto)
Peças deste passo:
  - Multímetro — tensão DC
O que fazer:
  * Robô no ar, sem USB. Conecte a bateria, chave em LIGA e meça.
Tabela:
    Onde medir         | Tem que dar
    -------------------+----------------------
    OUT+ / OUT− LM2596 | 4,9 – 5,1 V
    3V3 / GND ESP32    | 3,2 – 3,4 V
    VM / GND ponte H   | 7,0 – 8,4 V (bateria)
    VCC / GND ponte H  | 3,2 – 3,4 V
    Vcc / Gnd sonar    | 4,9 – 5,1 V
ATENÇÃO: Cheiro de queimado ou algo esquentando: desligue e desconecte a bateria na hora.
Quando terminar: passo 65 feito. Próximo: passo 66.

----------------------------------------------------------------------------------------------------
PASSO 66 de 69 · Bloco 12 · Capô e parafusos
----------------------------------------------------------------------------------------------------
Imagem: docs/manual/robo-capo.webp
Peças deste passo:
  - 4× Parafuso M3 × 45
O que fazer:
  * Encaixe o capô e aperte os 4 parafusos atravessando capô, plataforma e os dois espaçadores até a
    coluna.
Quando terminar: passo 66 feito. Próximo: passo 67.

####################################################################################################
BLOCO 13 · PROGRAMAR E LUTAR · passos 67 a 69
####################################################################################################
Para regravar é preciso tirar o capô: o USB fica para dentro, do lado da ponte H.
Imagem de capa: docs/manual/robo-pronto-topo.webp

----------------------------------------------------------------------------------------------------
PASSO 67 de 69 · Bloco 13 · Prepare a Arduino IDE
----------------------------------------------------------------------------------------------------
Imagem: nenhuma (passo só de texto)
O que fazer:
  * Placas: esp32 da Espressif. Bibliotecas: IRremote. Placa: DOIT ESP32 DEVKIT V1.
  * No código, o número é o nome D impresso ao lado do pino: 26 é o D26.
ATENÇÃO: Com o cabo USB ligado, a chave fica sempre em DESLIGA.
Quando terminar: passo 67 feito. Próximo: passo 68.

----------------------------------------------------------------------------------------------------
PASSO 68 de 69 · Bloco 13 · Modo teste
----------------------------------------------------------------------------------------------------
Imagem: nenhuma (passo só de texto)
O que fazer:
  * Grave com MODO_TESTE = true e abra o Monitor Serial em 115200.
  * Controle do juiz: aperte START e STOP e anote os códigos em IR_START e IR_STOP.
  * Robô no preto e no branco: a leitura cai no branco. Mão na frente: a distância cai.
  * Robô no ar, bateria conectada: digite e e d. Cada roda gira para a frente; se girar para trás,
    troque os dois fios daquele motor na ponte H.
Quando terminar: passo 68 feito. Próximo: passo 69.

----------------------------------------------------------------------------------------------------
PASSO 69 de 69 · Bloco 13 · Modo luta
----------------------------------------------------------------------------------------------------
Imagem: docs/manual/robo-pronto-topo.webp
O que fazer:
  * Grave com MODO_TESTE = false, feche o capô e tire o USB.
  * Na arena: chave em LIGA, robô no preto. LED piscando devagar = esperando o juiz. No START ele
    sai procurando; no STOP para.
Quando terminar: passo 69 feito. Fim do manual.

FIM DO MANUAL DESTA VERSÃO

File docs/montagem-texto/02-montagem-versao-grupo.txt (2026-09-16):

====================================================================================================
GUERREIROS DE REALENGO · MANUAL DE MONTAGEM EM TEXTO · VERSÃO DO GRUPO (só fio vermelho e preto; sonar, receptor e motores já vêm soldados)
====================================================================================================
Mesmo conteúdo da página
https://matheuscortes02.github.io/Guerreiros-de-Realengo-Robo-sumo/grupo.html (66 passos em 13
blocos). A numeração dos passos é a mesma do site. As imagens citadas estão no ZIP, nas pastas
indicadas. Esquerda e direita são sempre DO ROBÔ: sonar apontando para longe de você. Leia antes o
00-LEIA-PRIMEIRO.txt.

ÍNDICE
  Bloco  1 · Antes de começar · passos 1 a 4
  Bloco  2 · Sensores de borda · passos 5 a 14
  Bloco  3 · Sonar HC-SR04 · passos 15 a 19
  Bloco  4 · Receptor do juiz · passos 20 a 22
  Bloco  5 · Motores e rodas · passos 23 a 27
  Bloco  6 · Bateria, conector e chave · passos 28 a 34
  Bloco  7 · Regulador LM2596 · passos 35 a 38
  Bloco  8 · Emendas 3V3 e GND · passos 39 a 41
  Bloco  9 · Plataforma: ESP32 e ponte H · passos 42 a 49
  Bloco 10 · Plataforma no robô · passos 50 a 53
  Bloco 11 · Ponte H: energia e motores · passos 54 a 59
  Bloco 12 · Conferir e fechar · passos 60 a 63
  Bloco 13 · Programar e lutar · passos 64 a 66

####################################################################################################
BLOCO 1 · ANTES DE COMEÇAR · passos 1 a 4
####################################################################################################
Separe tudo, confira os resistores e aprenda a emendar. Cada bloco mostra, na primeira tela, os fios
que ele usa.
Imagem de capa: docs/grupo/preparo-pecas.webp

----------------------------------------------------------------------------------------------------
PASSO 1 de 66 · Bloco 1 · Separe as peças
----------------------------------------------------------------------------------------------------
Imagem: docs/grupo/preparo-pecas.webp
Na imagem: etiquetas “ESP32”, “ponte H”, “LM2596”, “HC-SR04”, “bateria”, “2 × TCRT5000”, “receptor”,
“2 × motor”, “chave SS12D00”, “conector”, “6 resistores”.
O que fazer:
  * Além disso: fio flexível 22 AWG e 26 AWG, termorretrátil, fita crepe, fita dupla-face, cola
    quente, velcro, termorretrátil fino de 1,5 mm (pinos do ESP32), 4 espaçadores de 12 mm e 4 de 5
    mm (plataforma), 4 parafusos M3 × 25 com porca e 4 M3 × 45.
CONFIRA: Ferramentas: ferro de solda, estanho com fluxo, alicate de corte, desencapador, multímetro,
    isqueiro ou soprador.
Quando terminar: passo 1 feito. Próximo: passo 2.

----------------------------------------------------------------------------------------------------
PASSO 2 de 66 · Bloco 1 · Confira os resistores
----------------------------------------------------------------------------------------------------
Imagem: docs/grupo/preparo-resistores.webp
Na imagem: etiquetas “100 Ω · 2 peças”, “10 kΩ · 2 peças”, “1 kΩ · 1 peça”, “2 kΩ · 1 peça”.
Peças deste passo:
  - 2× 100 Ω — marrom · preto · marrom
  - 2× 10 kΩ — marrom · preto · laranja
  - 1× 1 kΩ — marrom · preto · vermelho
  - 1× 2 kΩ — vermelho · preto · vermelho
O que fazer:
  * 100 Ω e 10 kΩ são quase iguais: só muda a terceira faixa. Meça cada um com o multímetro e separe
    em grupos.
ATENÇÃO: Trocar o 100 Ω pelo 10 kΩ não queima, mas o sensor de borda para de funcionar.
Quando terminar: passo 2 feito. Próximo: passo 3.

----------------------------------------------------------------------------------------------------
PASSO 3 de 66 · Bloco 1 · Numere cada fio
----------------------------------------------------------------------------------------------------
Imagem: docs/grupo/preparo-fios.webp
O que fazer:
  * Vocês só têm fio vermelho e preto: preto só no GND, vermelho em todo o resto. Com duas cores, a
    fita com o número nas duas pontas é obrigatória: é ela que diz qual fio é qual.
  * Corte cada fio no tamanho que aparece na primeira tela do bloco onde ele entra (e na lista de
    corte). As medidas já têm sobra.
Quando terminar: passo 3 feito. Próximo: passo 4.

----------------------------------------------------------------------------------------------------
PASSO 4 de 66 · Bloco 1 · Como emendar dois fios
----------------------------------------------------------------------------------------------------
Imagem: docs/grupo/preparo-solda.webp
Na imagem: etiquetas “1”, “2”, “3”, “4”.
O que fazer:
  * 1 Desencape 4 mm. 2 Passe o termorretrátil antes, torça as pontas e estanhe.
  * 3 Solde com 2 a 3 segundos de ferro, sem mexer até esfriar. 4 Puxe o tubo por cima e aqueça.
CONFIRA: Puxe de leve: a emenda não pode soltar. Solda boa é lisa e brilhante.
Quando terminar: passo 4 feito. Próximo: passo 5.

####################################################################################################
BLOCO 2 · SENSORES DE BORDA · passos 5 a 14
####################################################################################################
Dois TCRT5000 de 4 perninhas. Monte o esquerdo; o direito é igual, só muda o número dos fios.
Imagem de capa: docs/grupo/tcrt-t8.webp

FIOS QUE ENTRAM NESTE BLOCO (corte e numere com fita nas duas pontas antes de começar)
  - Fio 16 — vermelho — 26 AWG — corte com 50 mm
      de: emenda 3V3 (5 fios torcidos e soldados juntos)
      para: ponta de cima dos dois resistores (100 Ω e 10 kΩ) do sensor esquerdo, torcidas juntas
  - Fio 17 — vermelho — 26 AWG — corte com 70 mm
      de: emenda 3V3 (5 fios torcidos e soldados juntos)
      para: ponta de cima dos dois resistores (100 Ω e 10 kΩ) do sensor direito, torcidas juntas
  - Fio 20 — preto — 26 AWG — corte com 80 mm
      de: emenda GND (5 fios torcidos e soldados juntos)
      para: sensor esquerdo (TCRT5000), perna K
  - Fio 21 — preto — 26 AWG — corte com 50 mm
      de: emenda GND (5 fios torcidos e soldados juntos)
      para: sensor direito (TCRT5000), perna K
  - Fio 23 — vermelho — 26 AWG — corte com 150 mm
      de: sensor esquerdo (TCRT5000), perna C
      para: ESP32, pino D34 (fileira da FRENTE, a do EN…VIN, lado do sonar; 12º pino contando a partir da ponta do USB)
  - Fio 24 — vermelho — 26 AWG — corte com 110 mm
      de: sensor direito (TCRT5000), perna C
      para: ESP32, pino D35 (fileira da FRENTE, a do EN…VIN, lado do sonar; 11º pino contando a partir da ponta do USB)

----------------------------------------------------------------------------------------------------
PASSO 5 de 66 · Bloco 2 · Ache as pernas A, K, C e E
----------------------------------------------------------------------------------------------------
Imagem: docs/grupo/tcrt-t0.webp
Lupa (detalhe ampliado, no canto da imagem): docs/grupo/tcrt-t0-lupa.webp
Na imagem: etiquetas “A”, “K”, “C”, “E”, “lente azul”, “lente preta”.
Peças deste passo:
  - 1× TCRT5000 — 4 perninhas
O que fazer:
  * Debaixo da lente azul ficam A e K. Debaixo da lente preta, C e E. Na mesma fileira ficam A e C.
CONFIRA: Multímetro no modo diodo, vermelha numa perna do lado azul e preta na outra: por volta de
    1,1 V quer dizer vermelha no A. Marque o A.
Quando terminar: passo 5 feito. Próximo: passo 6.

----------------------------------------------------------------------------------------------------
PASSO 6 de 66 · Bloco 2 · 100 Ω na perna A
----------------------------------------------------------------------------------------------------
Imagem: docs/grupo/tcrt-t1.webp
Na imagem: etiquetas “100 Ω”.
Peças deste passo:
  - 1× Resistor 100 Ω — marrom · preto · marrom
  - Termorretrátil — pedaços de 1 a 2 cm
O que fazer:
  * Termorretrátil na perna A, encoste uma perna do 100 Ω ao lado e solde.
ATENÇÃO: Sem esse resistor, o LED do sensor queima na primeira vez que ligar.
Quando terminar: passo 6 feito. Próximo: passo 7.

----------------------------------------------------------------------------------------------------
PASSO 7 de 66 · Bloco 2 · 10 kΩ na perna C
----------------------------------------------------------------------------------------------------
Imagem: docs/grupo/tcrt-t2.webp
Na imagem: etiquetas “10 kΩ”.
Peças deste passo:
  - 1× Resistor 10 kΩ — marrom · preto · laranja
  - Termorretrátil — pedaços de 1 a 2 cm
O que fazer:
  * Mesma coisa na perna C com o 10 kΩ. Incline os dois resistores até as pontas de cima se tocarem.
Quando terminar: passo 7 feito. Próximo: passo 8.

----------------------------------------------------------------------------------------------------
PASSO 8 de 66 · Bloco 2 · Una as pernas K e E
----------------------------------------------------------------------------------------------------
Imagem: docs/grupo/tcrt-t3.webp
Na imagem: etiquetas “ponte”.
O que fazer:
  * Com uma sobra de perna de resistor, faça uma ponte entre K e E e solde nas duas.
CONFIRA: A ponte não pode encostar em A nem em C.
Quando terminar: passo 8 feito. Próximo: passo 9.

----------------------------------------------------------------------------------------------------
PASSO 9 de 66 · Bloco 2 · Fio 16 na ponta dos resistores
----------------------------------------------------------------------------------------------------
Imagem: docs/grupo/tcrt-t4.webp
Na imagem: círculo com o número do fio 16.
Peças deste passo:
  - Fio 16 — vermelho — 26 AWG — corte com 50 mm
  - Termorretrátil — pedaços de 1 a 2 cm
O que fazer:
  * Torça as pontas de cima dos dois resistores com a ponta do fio 16 (vermelho, 3,3 V) e solde.
Ligações deste passo, fio a fio:
  - Fio 16: (também aparece no passo 39: uma ponta é soldada aqui e a outra lá)
      uma ponta: emenda 3V3 (5 fios torcidos e soldados juntos)
      outra ponta: ponta de cima dos dois resistores (100 Ω e 10 kΩ) do sensor esquerdo, torcidas
        juntas
      caminho: embaixo da plataforma
      observação: chega na junção dos dois resistores do TCRT esquerdo
Quando terminar: passo 9 feito. Próximo: passo 10.

----------------------------------------------------------------------------------------------------
PASSO 10 de 66 · Bloco 2 · Fio 23 na perna C
----------------------------------------------------------------------------------------------------
Imagem: docs/grupo/tcrt-t5.webp
Na imagem: círculo com o número do fio 23.
Peças deste passo:
  - Fio 23 — vermelho — 26 AWG — corte com 150 mm
O que fazer:
  * Solde o fio 23 (vermelho, sinal) na perna C, no ponto onde já está o 10 kΩ.
Ligações deste passo, fio a fio:
  - Fio 23: (também aparece no passo 51: uma ponta é soldada aqui e a outra lá)
      uma ponta: sensor esquerdo (TCRT5000), perna C
      outra ponta: ESP32, pino D34 (fileira da FRENTE, a do EN…VIN, lado do sonar; 12º pino contando
        a partir da ponta do USB)
      caminho: sobe por baixo da plataforma até a ponta do pino
      observação: junto com o 10 kΩ na perna C
Quando terminar: passo 10 feito. Próximo: passo 11.

----------------------------------------------------------------------------------------------------
PASSO 11 de 66 · Bloco 2 · Fio 20 na ponte K–E
----------------------------------------------------------------------------------------------------
Imagem: docs/grupo/tcrt-t6.webp
Na imagem: círculo com o número do fio 20.
Peças deste passo:
  - Fio 20 — preto — 26 AWG — corte com 80 mm
O que fazer:
  * Solde o fio 20 (preto, GND) no meio da ponte entre K e E.
Ligações deste passo, fio a fio:
  - Fio 20: (também aparece no passo 40: uma ponta é soldada aqui e a outra lá)
      uma ponta: emenda GND (5 fios torcidos e soldados juntos)
      outra ponta: sensor esquerdo (TCRT5000), perna K
      caminho: embaixo da plataforma
      observação: chega na ponte entre as pernas K e E
Quando terminar: passo 11 feito. Próximo: passo 12.

----------------------------------------------------------------------------------------------------
PASSO 12 de 66 · Bloco 2 · Termorretrátil em tudo
----------------------------------------------------------------------------------------------------
Imagem: docs/grupo/tcrt-t7.webp
O que fazer:
  * Puxe os tubos por cima de cada solda e aqueça. Nenhum metal à mostra.
CONFIRA: Multímetro no bipe: entre o fio 16 e o fio 20 não pode apitar.
Quando terminar: passo 12 feito. Próximo: passo 13.

----------------------------------------------------------------------------------------------------
PASSO 13 de 66 · Bloco 2 · Monte o sensor direito igual · ×2
----------------------------------------------------------------------------------------------------
Imagem: docs/grupo/tcrt-t8.webp
Na imagem: círculos com os números dos fios 16, 23, 20, 17, 24, 21; etiquetas “esquerdo”, “direito”.
Peças deste passo:
  - 1× TCRT5000
  - 1× Resistor 100 Ω — marrom · preto · marrom
  - 1× Resistor 10 kΩ — marrom · preto · laranja
  - Fio 17 — vermelho — 26 AWG — corte com 70 mm
  - Fio 24 — vermelho — 26 AWG — corte com 110 mm
  - Fio 21 — preto — 26 AWG — corte com 50 mm
O que fazer:
  * Só mudam os fios: 17 no lugar do 16, 24 no lugar do 23 e 21 no lugar do 20.
Ligações deste passo, fio a fio:
  - Fio 17: (também aparece no passo 39: uma ponta é soldada aqui e a outra lá)
      uma ponta: emenda 3V3 (5 fios torcidos e soldados juntos)
      outra ponta: ponta de cima dos dois resistores (100 Ω e 10 kΩ) do sensor direito, torcidas
        juntas
      caminho: embaixo da plataforma
      observação: chega na junção dos dois resistores do TCRT direito
  - Fio 24: (também aparece no passo 51: uma ponta é soldada aqui e a outra lá)
      uma ponta: sensor direito (TCRT5000), perna C
      outra ponta: ESP32, pino D35 (fileira da FRENTE, a do EN…VIN, lado do sonar; 11º pino contando
        a partir da ponta do USB)
      caminho: sobe por baixo da plataforma até a ponta do pino
      observação: junto com o 10 kΩ na perna C
  - Fio 21: (também aparece no passo 40: uma ponta é soldada aqui e a outra lá)
      uma ponta: emenda GND (5 fios torcidos e soldados juntos)
      outra ponta: sensor direito (TCRT5000), perna K
      caminho: embaixo da plataforma
      observação: chega na ponte entre as pernas K e E
Quando terminar: passo 13 feito. Próximo: passo 14.

----------------------------------------------------------------------------------------------------
PASSO 14 de 66 · Bloco 2 · Cole nas janelas do piso
----------------------------------------------------------------------------------------------------
Imagem: docs/grupo/robo-tcrt.webp
Lupa (detalhe ampliado, no canto da imagem): docs/grupo/robo-tcrt-baixo.webp
Peças deste passo:
  - Cola quente
  - Cartão de visita — calço de 0,3 mm
O que fazer:
  * Chassi em pé numa mesa lisa, cartão dentro da janela, sensor com as lentes para baixo até
    encostar no cartão. Cole só por cima.
  * O sensor dos fios 16, 23 e 20 vai na janela do lado esquerdo do robô.
CONFIRA: Esquerda e direita são do robô: sonar apontando para longe de você.
Quando terminar: passo 14 feito. Próximo: passo 15.

####################################################################################################
BLOCO 3 · SONAR HC-SR04 · passos 15 a 19
####################################################################################################
O sonar já vem com os fios. Aqui você descobre qual é qual e monta o divisor que protege o ESP32 dos
5 V.
Imagem de capa: docs/grupo/sonar-h6.webp

FIOS QUE ENTRAM NESTE BLOCO (corte e numere com fita nas duas pontas antes de começar)
  - Fio 12 — vermelho — JÁ VEM SOLDADO na peça: não corte; confira que tem pelo menos 100 mm (se faltar, emende)
      de: LM2596, furo OUT+
      para: sonar HC-SR04, pino VCC
  - Fio 13 — preto — JÁ VEM SOLDADO na peça: não corte; confira que tem pelo menos 100 mm (se faltar, emende)
      de: LM2596, furo OUT−
      para: sonar HC-SR04, pino GND
  - Fio 25 — vermelho — JÁ VEM SOLDADO na peça: não corte; confira que tem pelo menos 150 mm (se faltar, emende)
      de: sonar HC-SR04, pino TRIG
      para: ESP32, pino D5 (fileira de TRÁS, a do D23…3V3; 8º pino contando a partir da ponta do USB)
  - Fio 26A — vermelho — JÁ VEM SOLDADO na peça: não corte; confira que tem pelo menos 70 mm (se faltar, emende)
      de: sonar HC-SR04, pino ECHO
      para: resistor 1 kΩ do divisor do sonar (perna emendada no fio 26A)
  - Fio 26B — vermelho — é o RESTO do fio do Echo depois de cortar o 26A; precisa ter pelo menos 110 mm (se faltar, emende)
      de: nó do divisor do sonar (perna do 1 kΩ onde também estão o 2 kΩ e o fio 26B)
      para: ESP32, pino D18 (fileira de TRÁS, a do D23…3V3; 9º pino contando a partir da ponta do USB)
  - Fio 26C — preto — 26 AWG — corte com 40 mm
      de: resistor 2 kΩ do divisor do sonar (perna livre, onde vai o fio 26C)
      para: emenda GND (5 fios torcidos e soldados juntos)

----------------------------------------------------------------------------------------------------
PASSO 15 de 66 · Bloco 3 · Descubra qual fio é de qual pino
----------------------------------------------------------------------------------------------------
Imagem: docs/grupo/sonar-h3.webp
Na imagem: círculos com os números dos fios 12, 25, 26A, 13.
Peças deste passo:
  - Fio 12 — vermelho — JÁ VEM SOLDADO na peça: não corte; confira que tem pelo menos 100 mm (se faltar, emende)
  - Fio 25 — vermelho — JÁ VEM SOLDADO na peça: não corte; confira que tem pelo menos 150 mm (se faltar, emende)
  - Fio 26A — vermelho — JÁ VEM SOLDADO na peça: não corte; confira que tem pelo menos 70 mm (se faltar, emende)
  - Fio 13 — preto — JÁ VEM SOLDADO na peça: não corte; confira que tem pelo menos 100 mm (se faltar, emende)
O que fazer:
  * O sonar já tem os 4 fios soldados. Multímetro no bipe: uma ponta no pino Vcc, a outra na ponta
    solta de cada fio. O que apitar é o fio 12.
  * Faça o mesmo: Trig → 25, Echo → 26A, Gnd → 13. Cole a fita com o número em cada um.
Ligações deste passo, fio a fio:
  - Fio 12: (também aparece no passo 38: uma ponta é soldada aqui e a outra lá)
      uma ponta: LM2596, furo OUT+
      outra ponta: sonar HC-SR04, pino VCC
      caminho: embaixo da plataforma
      observação: divide o furo OUT+ com o fio 10
  - Fio 25: (também aparece no passo 52: uma ponta é soldada aqui e a outra lá)
      uma ponta: sonar HC-SR04, pino TRIG
      outra ponta: ESP32, pino D5 (fileira de TRÁS, a do D23…3V3; 8º pino contando a partir da ponta
        do USB)
      caminho: sobe por baixo da plataforma até a ponta do pino
  - Fio 26A:
      uma ponta: sonar HC-SR04, pino ECHO
      outra ponta: resistor 1 kΩ do divisor do sonar (perna emendada no fio 26A)
      caminho: embaixo da plataforma
      observação: ECHO até o 1 kΩ (ainda 5 V)
  - Fio 13: (também aparece no passo 38: uma ponta é soldada aqui e a outra lá)
      uma ponta: LM2596, furo OUT−
      outra ponta: sonar HC-SR04, pino GND
      caminho: embaixo da plataforma
      observação: divide o furo OUT− com o fio 11
ATENÇÃO: Vcc e Gnd trocados queimam o sonar. Confira com o multímetro antes de numerar.
CONFIRA: Corte o fio do Echo a 70 mm do sensor: o pedaço preso ao sonar é o 26A e o resto vira o
    26B. Os fios 12 e 13 precisam ter pelo menos 100 mm e o 25, 150 mm; se faltar, emende.
Quando terminar: passo 15 feito. Próximo: passo 16.

----------------------------------------------------------------------------------------------------
PASSO 16 de 66 · Bloco 3 · 1 kΩ na ponta do fio 26A
----------------------------------------------------------------------------------------------------
Imagem: docs/grupo/sonar-h4.webp
Na imagem: etiquetas “1 kΩ”.
Peças deste passo:
  - 1× Resistor 1 kΩ — marrom · preto · vermelho
  - Termorretrátil — pedaços de 1 a 2 cm
O que fazer:
  * Emende o 1 kΩ na ponta solta do fio 26A, como uma emenda de dois fios.
Quando terminar: passo 16 feito. Próximo: passo 17.

----------------------------------------------------------------------------------------------------
PASSO 17 de 66 · Bloco 3 · O nó: 2 kΩ e fio 26B
----------------------------------------------------------------------------------------------------
Imagem: docs/grupo/sonar-h5.webp
Na imagem: círculo com o número do fio 26B; etiquetas “2 kΩ”.
Peças deste passo:
  - 1× Resistor 2 kΩ — vermelho · preto · vermelho
  - Fio 26B — vermelho — é o RESTO do fio do Echo depois de cortar o 26A; precisa ter pelo menos 110 mm (se faltar, emende)
  - Termorretrátil — pedaços de 1 a 2 cm
O que fazer:
  * Na outra perna do 1 kΩ, solde juntos uma perna do 2 kΩ e o fio 26B. O 26B leva o sinal ao ESP32.
Ligações deste passo, fio a fio:
  - Fio 26B: (também aparece no passo 52: uma ponta é soldada aqui e a outra lá)
      uma ponta: nó do divisor do sonar (perna do 1 kΩ onde também estão o 2 kΩ e o fio 26B)
      outra ponta: ESP32, pino D18 (fileira de TRÁS, a do D23…3V3; 9º pino contando a partir da
        ponta do USB)
      caminho: sobe por baixo da plataforma até a ponta do pino
      observação: sai do nó do divisor (já 3,3 V)
Quando terminar: passo 17 feito. Próximo: passo 18.

----------------------------------------------------------------------------------------------------
PASSO 18 de 66 · Bloco 3 · Fio 26C no 2 kΩ
----------------------------------------------------------------------------------------------------
Imagem: docs/grupo/sonar-h6.webp
Na imagem: círculo com o número do fio 26C.
Peças deste passo:
  - Fio 26C — preto — 26 AWG — corte com 40 mm
  - Termorretrátil — pedaços de 1 a 2 cm
O que fazer:
  * Na perna livre do 2 kΩ, solde o fio 26C (preto). Ele vai na emenda GND do bloco 8.
    Termorretrátil em tudo.
Ligações deste passo, fio a fio:
  - Fio 26C: (também aparece no passo 40: uma ponta é soldada aqui e a outra lá)
      uma ponta: resistor 2 kΩ do divisor do sonar (perna livre, onde vai o fio 26C)
      outra ponta: emenda GND (5 fios torcidos e soldados juntos)
      caminho: embaixo da plataforma
      observação: do 2 kΩ até a emenda GND
ATENÇÃO: O fio 26B nunca vai direto no Echo: sem o divisor, o sinal chega com 5 V e estraga o pino
    do ESP32.
Quando terminar: passo 18 feito. Próximo: passo 19.

----------------------------------------------------------------------------------------------------
PASSO 19 de 66 · Bloco 3 · Encaixe na frente do chassi
----------------------------------------------------------------------------------------------------
Imagem: docs/grupo/robo-hc.webp
Peças deste passo:
  - Cola quente
O que fazer:
  * Por dentro, encaixe os dois transdutores nos furos do meio da frente. Trave com cola quente na
    lateral da placa.
Quando terminar: passo 19 feito. Próximo: passo 20.

####################################################################################################
BLOCO 4 · RECEPTOR DO JUIZ · passos 20 a 22
####################################################################################################
Já vem soldado. Recebe START e STOP do juiz e fica no furo redondo da lateral DIREITA, oposta à
chave.
Imagem de capa: docs/grupo/receptor-i3.webp

FIOS QUE ENTRAM NESTE BLOCO (numere e confira o tamanho)
  - Fio 18 — vermelho — JÁ VEM SOLDADO na peça: não corte; confira que tem pelo menos 100 mm (se faltar, emende)
      de: emenda 3V3 (5 fios torcidos e soldados juntos)
      para: receptor do juiz, perna VCC
  - Fio 22 — preto — JÁ VEM SOLDADO na peça: não corte; confira que tem pelo menos 70 mm (se faltar, emende)
      de: emenda GND (5 fios torcidos e soldados juntos)
      para: receptor do juiz, perna GND
  - Fio 27 — vermelho — JÁ VEM SOLDADO na peça: não corte; confira que tem pelo menos 130 mm (se faltar, emende)
      de: receptor do juiz, perna OUT
      para: ESP32, pino D19 (fileira de TRÁS, a do D23…3V3; 10º pino contando a partir da ponta do USB)

----------------------------------------------------------------------------------------------------
PASSO 20 de 66 · Bloco 4 · Descubra qual fio é qual
----------------------------------------------------------------------------------------------------
Imagem: docs/grupo/receptor-i1.webp
Na imagem: etiquetas “OUT”, “GND”, “VCC”, “S”, “+”, “−”.
Peças deste passo:
  - Fio 27 — vermelho — JÁ VEM SOLDADO na peça: não corte; confira que tem pelo menos 130 mm (se faltar, emende)
  - Fio 22 — preto — JÁ VEM SOLDADO na peça: não corte; confira que tem pelo menos 70 mm (se faltar, emende)
  - Fio 18 — vermelho — JÁ VEM SOLDADO na peça: não corte; confira que tem pelo menos 100 mm (se faltar, emende)
O que fazer:
  * O receptor já tem os 3 fios. Bolinha de frente, pernas para baixo: OUT à esquerda, GND no meio,
    VCC à direita (na KY-022: S, +, −).
  * Siga cada perna até o fio e numere: OUT → 27, GND → 22, VCC → 18.
Ligações deste passo, fio a fio:
  - Fio 27: (também aparece no passo 52: uma ponta é soldada aqui e a outra lá)
      uma ponta: receptor do juiz, perna OUT
      outra ponta: ESP32, pino D19 (fileira de TRÁS, a do D23…3V3; 10º pino contando a partir da
        ponta do USB)
      caminho: sobe por baixo da plataforma até a ponta do pino
  - Fio 22: (também aparece no passo 40: uma ponta é soldada aqui e a outra lá)
      uma ponta: emenda GND (5 fios torcidos e soldados juntos)
      outra ponta: receptor do juiz, perna GND
      caminho: embaixo da plataforma
  - Fio 18: (também aparece no passo 39: uma ponta é soldada aqui e a outra lá)
      uma ponta: emenda 3V3 (5 fios torcidos e soldados juntos)
      outra ponta: receptor do juiz, perna VCC
      caminho: embaixo da plataforma
ATENÇÃO: O pino do meio muda: no VS1838B é GND, na KY-022 é +. Trocado, queima o receptor.
Quando terminar: passo 20 feito. Próximo: passo 21.

----------------------------------------------------------------------------------------------------
PASSO 21 de 66 · Bloco 4 · Dobre as pernas e isole
----------------------------------------------------------------------------------------------------
Imagem: docs/grupo/receptor-i3.webp
Na imagem: círculos com os números dos fios 27, 22, 18.
Peças deste passo:
  - Termorretrátil — pedaços de 1 a 2 cm
O que fazer:
  * Se as pernas estiverem retas, dobre para trás logo abaixo do corpo, segurando a perna com
    alicate para não forçar a solda. Termorretrátil em cada perna.
CONFIRA: Nenhuma perna pode encostar na outra.
Quando terminar: passo 21 feito. Próximo: passo 22.

----------------------------------------------------------------------------------------------------
PASSO 22 de 66 · Bloco 4 · Encaixe no furo redondo da lateral direita
----------------------------------------------------------------------------------------------------
Imagem: docs/grupo/robo-ir.webp
Lupa (detalhe ampliado, no canto da imagem): docs/grupo/robo-ir-lupa.webp
Peças deste passo:
  - Cola quente
O que fazer:
  * Por dentro do chassi, empurre o receptor para dentro do furo redondo da lateral direita (lado
    oposto da chave), bolinha para fora. Trave com cola quente no corpo.
CONFIRA: Por fora do robô, você tem que ver a bolinha preta no meio do furo.
Quando terminar: passo 22 feito. Próximo: passo 23.

####################################################################################################
BLOCO 5 · MOTORES E RODAS · passos 23 a 27
####################################################################################################
Os motores já vêm com os fios: numere, teste e monte.
Imagem de capa: docs/grupo/robo-rodas.webp

FIOS QUE ENTRAM NESTE BLOCO (numere e confira o tamanho)
  - Fio 6 — vermelho — JÁ VEM SOLDADO na peça: não corte; confira que tem pelo menos 160 mm (se faltar, emende)
      de: motor esquerdo, um dos dois terminais
      para: ponte H TB6612, furo A01 (fileira de energia, a do VM; 4º furo)
  - Fio 7 — vermelho — JÁ VEM SOLDADO na peça: não corte; confira que tem pelo menos 160 mm (se faltar, emende)
      de: motor esquerdo, um dos dois terminais
      para: ponte H TB6612, furo A02 (fileira de energia, a do VM; 5º furo)
  - Fio 8 — vermelho — JÁ VEM SOLDADO na peça: não corte; confira que tem pelo menos 160 mm (se faltar, emende)
      de: motor direito, um dos dois terminais
      para: ponte H TB6612, furo B01 (fileira de energia, a do VM; 7º furo)
  - Fio 9 — vermelho — JÁ VEM SOLDADO na peça: não corte; confira que tem pelo menos 160 mm (se faltar, emende)
      de: motor direito, um dos dois terminais
      para: ponte H TB6612, furo B02 (fileira de energia, a do VM; 6º furo)

----------------------------------------------------------------------------------------------------
PASSO 23 de 66 · Bloco 5 · Numere os fios dos motores
----------------------------------------------------------------------------------------------------
Imagem: docs/grupo/motores-m1.webp
Na imagem: círculos com os números dos fios 6, 7, 8, 9; etiquetas “esquerdo”, “direito”.
Peças deste passo:
  - Fio 6 — vermelho — JÁ VEM SOLDADO na peça: não corte; confira que tem pelo menos 160 mm (se faltar, emende)
  - Fio 7 — vermelho — JÁ VEM SOLDADO na peça: não corte; confira que tem pelo menos 160 mm (se faltar, emende)
  - Fio 8 — vermelho — JÁ VEM SOLDADO na peça: não corte; confira que tem pelo menos 160 mm (se faltar, emende)
  - Fio 9 — vermelho — JÁ VEM SOLDADO na peça: não corte; confira que tem pelo menos 160 mm (se faltar, emende)
O que fazer:
  * Os motores já têm 2 fios cada. Motor esquerdo: 6 e 7. Motor direito: 8 e 9. Tanto faz qual é
    qual.
Ligações deste passo, fio a fio:
  - Fio 6: (também aparece no passo 57: uma ponta é soldada aqui e a outra lá)
      uma ponta: motor esquerdo, um dos dois terminais
      outra ponta: ponte H TB6612, furo A01 (fileira de energia, a do VM; 4º furo)
      caminho: furo Ø6 da tampa e rasgo R4
  - Fio 7: (também aparece no passo 57: uma ponta é soldada aqui e a outra lá)
      uma ponta: motor esquerdo, um dos dois terminais
      outra ponta: ponte H TB6612, furo A02 (fileira de energia, a do VM; 5º furo)
      caminho: furo Ø6 da tampa e rasgo R4
  - Fio 8: (também aparece no passo 58: uma ponta é soldada aqui e a outra lá)
      uma ponta: motor direito, um dos dois terminais
      outra ponta: ponte H TB6612, furo B01 (fileira de energia, a do VM; 7º furo)
      caminho: furo Ø6 da tampa e rasgo R4
  - Fio 9: (também aparece no passo 58: uma ponta é soldada aqui e a outra lá)
      uma ponta: motor direito, um dos dois terminais
      outra ponta: ponte H TB6612, furo B02 (fileira de energia, a do VM; 6º furo)
      caminho: furo Ø6 da tampa e rasgo R4
CONFIRA: Teste antes de fechar: encoste por 1 segundo os dois fios de um motor no + e no − da
    bateria. Ele tem que girar.
Quando terminar: passo 23 feito. Próximo: passo 24.

----------------------------------------------------------------------------------------------------
PASSO 24 de 66 · Bloco 5 · Isole a traseira
----------------------------------------------------------------------------------------------------
Imagem: docs/grupo/motores-m2.webp
Na imagem: etiquetas “fita isolante”.
Peças deste passo:
  - Fita isolante
O que fazer:
  * Fita isolante na traseira de cada motor: os dois se encostam dentro da caixa.
ATENÇÃO: Terminal de um motor encostando no do outro dá curto na ponte H.
Quando terminar: passo 24 feito. Próximo: passo 25.

----------------------------------------------------------------------------------------------------
PASSO 25 de 66 · Bloco 5 · Motores na caixa
----------------------------------------------------------------------------------------------------
Imagem: docs/grupo/robo-motores.webp
O que fazer:
  * Cada motor entra pela sua lateral, eixo para fora. O esquerdo pelo lado esquerdo do robô.
Quando terminar: passo 25 feito. Próximo: passo 26.

----------------------------------------------------------------------------------------------------
PASSO 26 de 66 · Bloco 5 · Tampa e parafusos
----------------------------------------------------------------------------------------------------
Imagem: docs/grupo/robo-tampa.webp
Peças deste passo:
  - 4× Parafuso M3 × 25 — com porca
O que fazer:
  * Passe os 4 fios pelo furo do meio da tampa, encaixe a tampa e parafuse a caixa no chassi.
Quando terminar: passo 26 feito. Próximo: passo 27.

----------------------------------------------------------------------------------------------------
PASSO 27 de 66 · Bloco 5 · Rodas
----------------------------------------------------------------------------------------------------
Imagem: docs/grupo/robo-rodas.webp
Peças deste passo:
  - 2× Roda 32 mm
O que fazer:
  * Aperte o parafuso da roda na parte plana do eixo. Gire com a mão: não pode raspar.
Quando terminar: passo 27 feito. Próximo: passo 28.

####################################################################################################
BLOCO 6 · BATERIA, CONECTOR E CHAVE · passos 28 a 34
####################################################################################################
A chave SS12D00 aguenta 0,5 A: liga só a eletrônica. Os motores recebem a bateria direto pelo fio 3.
Imagem de capa: docs/grupo/chave-c5.webp

FIOS QUE ENTRAM NESTE BLOCO (corte e numere com fita nas duas pontas antes de começar)
  - Fio 1 — vermelho — 22 AWG — corte com 60 mm
      de: conector da bateria, fio + vermelho
      para: chave SS12D00, pino COM (o do meio)
  - Fio 2 — vermelho — 22 AWG — corte com 60 mm
      de: chave SS12D00, pino P1 (o do lado que LIGA, achado com o multímetro)
      para: LM2596, furo IN+
  - Fio 3 — vermelho — 22 AWG — corte com 120 mm
      de: conector da bateria, fio + vermelho
      para: ponte H TB6612, furo VM (fileira de energia, a do VM; 1º furo)
  - Fio 4 — preto — 22 AWG — corte com 120 mm
      de: conector da bateria, fio − preto
      para: ponte H TB6612, furo GND (fileira de energia, a do VM; 3º furo)
  - Fio 5 — preto — 22 AWG — corte com 50 mm
      de: conector da bateria, fio − preto
      para: LM2596, furo IN−

----------------------------------------------------------------------------------------------------
PASSO 28 de 66 · Bloco 6 · Bateria com velcro
----------------------------------------------------------------------------------------------------
Imagem: docs/grupo/robo-bateria.webp
Peças deste passo:
  - 1× Bateria 7,4 V
  - 2 Tiras de velcro
O que fazer:
  * Velcro no piso e na bateria, deitada no fundo. Velcro e não cola: ela sai para carregar.
Quando terminar: passo 28 feito. Próximo: passo 29.

----------------------------------------------------------------------------------------------------
PASSO 29 de 66 · Bloco 6 · Descubra o lado que liga
----------------------------------------------------------------------------------------------------
Imagem: docs/grupo/chave-c1.webp
Lupa (detalhe ampliado, no canto da imagem): docs/grupo/chave-c1-lupa.webp
Na imagem: etiquetas “P1”, “COM”, “P2”, “+”, “−”.
Peças deste passo:
  - 1× Chave SS12D00 — 3 perninhas
  - 1× Conector — lado do robô
O que fazer:
  * O pino do meio é o COM. Bipe entre o COM e um pino do lado; empurre o botão: para um lado apita.
    Esse pino é o P1 e essa posição é LIGA.
Quando terminar: passo 29 feito. Próximo: passo 30.

----------------------------------------------------------------------------------------------------
PASSO 30 de 66 · Bloco 6 · Fio 1: conector + até o COM
----------------------------------------------------------------------------------------------------
Imagem: docs/grupo/chave-c2.webp
Na imagem: círculo com o número do fio 1.
Peças deste passo:
  - Fio 1 — vermelho — 22 AWG — corte com 60 mm
  - Termorretrátil — pedaços de 1 a 2 cm
O que fazer:
  * Fio 1 no fio vermelho (+) do conector e a outra ponta no pino do meio da chave.
Ligações deste passo, fio a fio:
  - Fio 1:
      uma ponta: conector da bateria, fio + vermelho
      outra ponta: chave SS12D00, pino COM (o do meio)
      caminho: embaixo da plataforma
      observação: vermelho do conector da bateria, junto com o fio 3; na chave, pino do meio
ATENÇÃO: Solde com a bateria desconectada. Um toque do + no − derrete os fios.
Quando terminar: passo 30 feito. Próximo: passo 31.

----------------------------------------------------------------------------------------------------
PASSO 31 de 66 · Bloco 6 · Fio 2 no P1
----------------------------------------------------------------------------------------------------
Imagem: docs/grupo/chave-c3.webp
Na imagem: círculo com o número do fio 2.
Peças deste passo:
  - Fio 2 — vermelho — 22 AWG — corte com 60 mm
  - Termorretrátil — pedaços de 1 a 2 cm
O que fazer:
  * Fio 2 no P1. Ele vai ao IN+ do LM2596. O terceiro pino fica vazio.
Ligações deste passo, fio a fio:
  - Fio 2: (também aparece no passo 36: uma ponta é soldada aqui e a outra lá)
      uma ponta: chave SS12D00, pino P1 (o do lado que LIGA, achado com o multímetro)
      outra ponta: LM2596, furo IN+
      caminho: embaixo da plataforma
      observação: na chave, o pino do lado que liga (confira com o multímetro)
Quando terminar: passo 31 feito. Próximo: passo 32.

----------------------------------------------------------------------------------------------------
PASSO 32 de 66 · Bloco 6 · Fio 3 no + do conector
----------------------------------------------------------------------------------------------------
Imagem: docs/grupo/chave-c4.webp
Na imagem: círculo com o número do fio 3.
Peças deste passo:
  - Fio 3 — vermelho — 22 AWG — corte com 120 mm
O que fazer:
  * No mesmo ponto do fio 1, solde o fio 3. Ele vai direto ao VM da ponte H.
Ligações deste passo, fio a fio:
  - Fio 3: (também aparece no passo 54: uma ponta é soldada aqui e a outra lá)
      uma ponta: conector da bateria, fio + vermelho
      outra ponta: ponte H TB6612, furo VM (fileira de energia, a do VM; 1º furo)
      caminho: sobe pelo rasgo R4
      observação: vermelho do conector da bateria, junto com o fio 1: os motores não passam pela
        chave
CONFIRA: O + do conector fica com dois fios: 1 e 3.
Quando terminar: passo 32 feito. Próximo: passo 33.

----------------------------------------------------------------------------------------------------
PASSO 33 de 66 · Bloco 6 · Fios 4 e 5 no − do conector
----------------------------------------------------------------------------------------------------
Imagem: docs/grupo/chave-c5.webp
Na imagem: círculos com os números dos fios 4, 5.
Peças deste passo:
  - Fio 4 — preto — 22 AWG — corte com 120 mm
  - Fio 5 — preto — 22 AWG — corte com 50 mm
  - Termorretrátil — pedaços de 1 a 2 cm
O que fazer:
  * No fio preto (−) do conector, solde juntos os fios 4 e 5. Termorretrátil nas duas emendas.
Ligações deste passo, fio a fio:
  - Fio 4: (também aparece no passo 56: uma ponta é soldada aqui e a outra lá)
      uma ponta: conector da bateria, fio − preto
      outra ponta: ponte H TB6612, furo GND (fileira de energia, a do VM; 3º furo)
      caminho: sobe pelo rasgo R4
      observação: preto do conector da bateria, junto com o fio 5
  - Fio 5: (também aparece no passo 36: uma ponta é soldada aqui e a outra lá)
      uma ponta: conector da bateria, fio − preto
      outra ponta: LM2596, furo IN−
      caminho: embaixo da plataforma
      observação: preto do conector da bateria, junto com o fio 4
CONFIRA: Bipe entre o + e o − do conector: não pode apitar.
Quando terminar: passo 33 feito. Próximo: passo 34.

----------------------------------------------------------------------------------------------------
PASSO 34 de 66 · Bloco 6 · Chave na lateral esquerda
----------------------------------------------------------------------------------------------------
Imagem: docs/grupo/robo-chave.webp
Lupa (detalhe ampliado, no canto da imagem): docs/grupo/robo-chave-lupa.webp
Peças deste passo:
  - Cola quente
O que fazer:
  * Cole a chave no furo retangular da lateral esquerda, botão para fora. O conector fica em cima da
    bateria.
Quando terminar: passo 34 feito. Próximo: passo 35.

####################################################################################################
BLOCO 7 · REGULADOR LM2596 · passos 35 a 38
####################################################################################################
Colado em cima da bateria. Transforma 7,4 V em 5 V e precisa ser ajustado antes de ligar a saída.
Imagem de capa: docs/grupo/robo-lm-hc.webp

FIOS QUE ENTRAM NESTE BLOCO (corte e numere com fita nas duas pontas antes de começar)
  - Fio 10 — vermelho — 26 AWG — corte com 130 mm
      de: LM2596, furo OUT+
      para: ESP32, pino VIN (fileira da FRENTE, a do EN…VIN, lado do sonar; 1º pino contando a partir da ponta do USB)
  - Fio 11 — preto — 26 AWG — corte com 120 mm
      de: LM2596, furo OUT−
      para: ESP32, pino GND (fileira da FRENTE, a do EN…VIN, lado do sonar; 2º pino contando a partir da ponta do USB)

----------------------------------------------------------------------------------------------------
PASSO 35 de 66 · Bloco 7 · Cole em cima da bateria
----------------------------------------------------------------------------------------------------
Imagem: docs/grupo/robo-lm.webp
Peças deste passo:
  - 1× LM2596
  - Fita dupla-face
O que fazer:
  * Entrada (IN) para o lado esquerdo, perto da chave; saída (OUT) para o direito.
Quando terminar: passo 35 feito. Próximo: passo 36.

----------------------------------------------------------------------------------------------------
PASSO 36 de 66 · Bloco 7 · Fios 2 e 5 na entrada
----------------------------------------------------------------------------------------------------
Imagem: docs/grupo/robo-lm-entrada.webp
Lupa (detalhe ampliado, no canto da imagem): docs/grupo/robo-lm-entrada-lupa.webp
Peças deste passo:
  - Fio 2 — vermelho — 22 AWG — corte com 60 mm
  - Fio 5 — preto — 22 AWG — corte com 50 mm
O que fazer:
  * Fio 2 (da chave) no IN+. Fio 5 (do conector) no IN−. Leia o + e o − impressos.
Ligações deste passo, fio a fio:
  - Fio 2: (também aparece no passo 31: uma ponta é soldada aqui e a outra lá)
      uma ponta: chave SS12D00, pino P1 (o do lado que LIGA, achado com o multímetro)
      outra ponta: LM2596, furo IN+
      caminho: embaixo da plataforma
      observação: na chave, o pino do lado que liga (confira com o multímetro)
  - Fio 5: (também aparece no passo 33: uma ponta é soldada aqui e a outra lá)
      uma ponta: conector da bateria, fio − preto
      outra ponta: LM2596, furo IN−
      caminho: embaixo da plataforma
      observação: preto do conector da bateria, junto com o fio 4
ATENÇÃO: Entrada invertida queima o LM2596 na hora.
Quando terminar: passo 36 feito. Próximo: passo 37.

----------------------------------------------------------------------------------------------------
PASSO 37 de 66 · Bloco 7 · Ajuste para 5,00 V
----------------------------------------------------------------------------------------------------
Imagem: docs/grupo/robo-lm-ajuste.webp
Peças deste passo:
  - Multímetro — tensão DC
  - Chave de fenda pequena
O que fazer:
  * Nada na saída. Bateria conectada, chave em LIGA. Vermelha no OUT+, preta no OUT−.
  * Gire o parafuso dourado: horário sobe. Pare em 5,00 V (pode levar 10 a 20 voltas). Depois
    desligue e desconecte a bateria.
ATENÇÃO: Ele vem de fábrica numa tensão qualquer, às vezes mais de 30 V. Ligar a saída antes de
    ajustar queima o sonar e o ESP32.
Quando terminar: passo 37 feito. Próximo: passo 38.

----------------------------------------------------------------------------------------------------
PASSO 38 de 66 · Bloco 7 · Fios 12, 10, 13 e 11 na saída
----------------------------------------------------------------------------------------------------
Imagem: docs/grupo/robo-lm-hc.webp
Peças deste passo:
  - Fio 12 — vermelho — JÁ VEM SOLDADO na peça: não corte; confira que tem pelo menos 100 mm (se faltar, emende)
  - Fio 10 — vermelho — 26 AWG — corte com 130 mm
  - Fio 13 — preto — JÁ VEM SOLDADO na peça: não corte; confira que tem pelo menos 100 mm (se faltar, emende)
  - Fio 11 — preto — 26 AWG — corte com 120 mm
O que fazer:
  * No OUT+, juntos: 12 (sonar) e 10 (vai ao VIN do ESP32). No OUT−, juntos: 13 (sonar) e 11 (vai ao
    GND do ESP32).
Ligações deste passo, fio a fio:
  - Fio 12: (também aparece no passo 15: uma ponta é soldada aqui e a outra lá)
      uma ponta: LM2596, furo OUT+
      outra ponta: sonar HC-SR04, pino VCC
      caminho: embaixo da plataforma
      observação: divide o furo OUT+ com o fio 10
  - Fio 10: (também aparece no passo 51: uma ponta é soldada aqui e a outra lá)
      uma ponta: LM2596, furo OUT+
      outra ponta: ESP32, pino VIN (fileira da FRENTE, a do EN…VIN, lado do sonar; 1º pino contando
        a partir da ponta do USB)
      caminho: sobe por baixo da plataforma até a ponta do pino
      observação: divide o furo OUT+ com o fio 12
  - Fio 13: (também aparece no passo 15: uma ponta é soldada aqui e a outra lá)
      uma ponta: LM2596, furo OUT−
      outra ponta: sonar HC-SR04, pino GND
      caminho: embaixo da plataforma
      observação: divide o furo OUT− com o fio 11
  - Fio 11: (também aparece no passo 51: uma ponta é soldada aqui e a outra lá)
      uma ponta: LM2596, furo OUT−
      outra ponta: ESP32, pino GND (fileira da FRENTE, a do EN…VIN, lado do sonar; 2º pino contando
        a partir da ponta do USB)
      caminho: sobe por baixo da plataforma até a ponta do pino
      observação: divide o furo OUT− com o fio 13
CONFIRA: Cada furo da saída fica com dois fios.
Quando terminar: passo 38 feito. Próximo: passo 39.

####################################################################################################
BLOCO 8 · EMENDAS 3V3 E GND · passos 39 a 41
####################################################################################################
Um pino do ESP32 alimenta vários sensores porque o fio se divide numa emenda. São duas: 3V3 e GND.
Imagem de capa: docs/grupo/robo-emendas.webp

FIOS QUE ENTRAM NESTE BLOCO (corte e numere com fita nas duas pontas antes de começar)
  - Fio 14 — vermelho — 26 AWG — corte com 110 mm
      de: ESP32, pino 3V3 (fileira de TRÁS, a do D23…3V3; 1º pino contando a partir da ponta do USB)
      para: emenda 3V3 (5 fios torcidos e soldados juntos)
  - Fio 15 — preto — 26 AWG — corte com 110 mm
      de: ESP32, pino GND (fileira de TRÁS, a do D23…3V3; 2º pino contando a partir da ponta do USB)
      para: emenda GND (5 fios torcidos e soldados juntos)
  - Fio 19 — vermelho — 26 AWG — corte com 130 mm
      de: emenda 3V3 (5 fios torcidos e soldados juntos)
      para: ponte H TB6612, furo VCC (fileira de energia, a do VM; 2º furo)

----------------------------------------------------------------------------------------------------
PASSO 39 de 66 · Bloco 8 · Emenda 3V3
----------------------------------------------------------------------------------------------------
Imagem: docs/grupo/emendas-e1.webp
Na imagem: círculos com os números dos fios 14, 16, 17, 18, 19.
Peças deste passo:
  - Fio 14 — vermelho — 26 AWG — corte com 110 mm
  - Fio 16 — vermelho — 26 AWG — corte com 50 mm
  - Fio 17 — vermelho — 26 AWG — corte com 70 mm
  - Fio 18 — vermelho — JÁ VEM SOLDADO na peça: não corte; confira que tem pelo menos 100 mm (se faltar, emende)
  - Fio 19 — vermelho — 26 AWG — corte com 130 mm
  - Termorretrátil — pedaços de 1 a 2 cm
O que fazer:
  * Termorretrátil grosso num fio, desencape 5 mm de cada ponta, torça as cinco juntas e solde.
  * 16 e 17 (sensores), 18 (receptor), 19 (ponte H), 14 (3V3 do ESP32).
Ligações deste passo, fio a fio:
  - Fio 14: (também aparece no passo 52: uma ponta é soldada aqui e a outra lá)
      uma ponta: ESP32, pino 3V3 (fileira de TRÁS, a do D23…3V3; 1º pino contando a partir da ponta
        do USB)
      outra ponta: emenda 3V3 (5 fios torcidos e soldados juntos)
      caminho: sobe por baixo da plataforma até a ponta do pino
  - Fio 16: (também aparece no passo 9: uma ponta é soldada aqui e a outra lá)
      uma ponta: emenda 3V3 (5 fios torcidos e soldados juntos)
      outra ponta: ponta de cima dos dois resistores (100 Ω e 10 kΩ) do sensor esquerdo, torcidas
        juntas
      caminho: embaixo da plataforma
      observação: chega na junção dos dois resistores do TCRT esquerdo
  - Fio 17: (também aparece no passo 13: uma ponta é soldada aqui e a outra lá)
      uma ponta: emenda 3V3 (5 fios torcidos e soldados juntos)
      outra ponta: ponta de cima dos dois resistores (100 Ω e 10 kΩ) do sensor direito, torcidas
        juntas
      caminho: embaixo da plataforma
      observação: chega na junção dos dois resistores do TCRT direito
  - Fio 18: (também aparece no passo 20: uma ponta é soldada aqui e a outra lá)
      uma ponta: emenda 3V3 (5 fios torcidos e soldados juntos)
      outra ponta: receptor do juiz, perna VCC
      caminho: embaixo da plataforma
  - Fio 19: (também aparece no passo 55: uma ponta é soldada aqui e a outra lá)
      uma ponta: emenda 3V3 (5 fios torcidos e soldados juntos)
      outra ponta: ponte H TB6612, furo VCC (fileira de energia, a do VM; 2º furo)
      caminho: sobe pelo rasgo R2
ATENÇÃO: Só os fios 14, 16, 17, 18 e 19. Um fio de GND aqui é curto direto no ESP32.
Quando terminar: passo 39 feito. Próximo: passo 40.

----------------------------------------------------------------------------------------------------
PASSO 40 de 66 · Bloco 8 · Emenda GND
----------------------------------------------------------------------------------------------------
Imagem: docs/grupo/emendas-e2.webp
Na imagem: círculos com os números dos fios 15, 20, 21, 22, 26C.
Peças deste passo:
  - Fio 15 — preto — 26 AWG — corte com 110 mm
  - Fio 20 — preto — 26 AWG — corte com 80 mm
  - Fio 21 — preto — 26 AWG — corte com 50 mm
  - Fio 22 — preto — JÁ VEM SOLDADO na peça: não corte; confira que tem pelo menos 70 mm (se faltar, emende)
  - Fio 26C — preto — 26 AWG — corte com 40 mm
  - Termorretrátil — pedaços de 1 a 2 cm
O que fazer:
  * Cinco pretos: 20 e 21 (sensores), 22 (receptor), 26C (divisor do sonar), 15 (GND do ESP32).
Ligações deste passo, fio a fio:
  - Fio 15: (também aparece no passo 52: uma ponta é soldada aqui e a outra lá)
      uma ponta: ESP32, pino GND (fileira de TRÁS, a do D23…3V3; 2º pino contando a partir da ponta
        do USB)
      outra ponta: emenda GND (5 fios torcidos e soldados juntos)
      caminho: sobe por baixo da plataforma até a ponta do pino
  - Fio 20: (também aparece no passo 11: uma ponta é soldada aqui e a outra lá)
      uma ponta: emenda GND (5 fios torcidos e soldados juntos)
      outra ponta: sensor esquerdo (TCRT5000), perna K
      caminho: embaixo da plataforma
      observação: chega na ponte entre as pernas K e E
  - Fio 21: (também aparece no passo 13: uma ponta é soldada aqui e a outra lá)
      uma ponta: emenda GND (5 fios torcidos e soldados juntos)
      outra ponta: sensor direito (TCRT5000), perna K
      caminho: embaixo da plataforma
      observação: chega na ponte entre as pernas K e E
  - Fio 22: (também aparece no passo 20: uma ponta é soldada aqui e a outra lá)
      uma ponta: emenda GND (5 fios torcidos e soldados juntos)
      outra ponta: receptor do juiz, perna GND
      caminho: embaixo da plataforma
  - Fio 26C: (também aparece no passo 18: uma ponta é soldada aqui e a outra lá)
      uma ponta: resistor 2 kΩ do divisor do sonar (perna livre, onde vai o fio 26C)
      outra ponta: emenda GND (5 fios torcidos e soldados juntos)
      caminho: embaixo da plataforma
      observação: do 2 kΩ até a emenda GND
CONFIRA: O GND do sonar e o da ponte H não entram aqui.
Quando terminar: passo 40 feito. Próximo: passo 41.

----------------------------------------------------------------------------------------------------
PASSO 41 de 66 · Bloco 8 · Encolha e acomode
----------------------------------------------------------------------------------------------------
Imagem: docs/grupo/robo-emendas.webp
O que fazer:
  * Aqueça os tubos e acomode as emendas atrás do sonar, em cima da borda da placa dele.
CONFIRA: Bipe entre um fio da emenda 3V3 e um da GND: não pode apitar.
Quando terminar: passo 41 feito. Próximo: passo 42.

####################################################################################################
BLOCO 9 · PLATAFORMA: ESP32 E PONTE H · passos 42 a 49
####################################################################################################
Na bancada, fora do robô. O ESP32 fica apoiado na plataforma com os pinos atravessando os rasgos, e
todo fio do ESP32 é soldado na ponta do pino, por baixo.
Imagem de capa: docs/grupo/robo-plat-tb.webp

FIOS QUE ENTRAM NESTE BLOCO (corte e numere com fita nas duas pontas antes de começar)
  - Fio 28 — vermelho — 26 AWG — corte com 110 mm
      de: ponte H TB6612, furo PWMA (fileira de controle, a do PWMA; 1º furo)
      para: ESP32, pino D25 (fileira da FRENTE, a do EN…VIN, lado do sonar; 8º pino contando a partir da ponta do USB)
  - Fio 29 — vermelho — 26 AWG — corte com 100 mm
      de: ponte H TB6612, furo AIN2 (fileira de controle, a do PWMA; 2º furo)
      para: ESP32, pino D27 (fileira da FRENTE, a do EN…VIN, lado do sonar; 6º pino contando a partir da ponta do USB)
  - Fio 30 — vermelho — 26 AWG — corte com 100 mm
      de: ponte H TB6612, furo AIN1 (fileira de controle, a do PWMA; 3º furo)
      para: ESP32, pino D26 (fileira da FRENTE, a do EN…VIN, lado do sonar; 7º pino contando a partir da ponta do USB)
  - Fio 31 — vermelho — 26 AWG — corte com 90 mm
      de: ponte H TB6612, furo STBY (fileira de controle, a do PWMA; 4º furo)
      para: ESP32, pino D13 (fileira da FRENTE, a do EN…VIN, lado do sonar; 3º pino contando a partir da ponta do USB)
  - Fio 32 — vermelho — 26 AWG — corte com 100 mm
      de: ponte H TB6612, furo BIN1 (fileira de controle, a do PWMA; 5º furo)
      para: ESP32, pino D32 (fileira da FRENTE, a do EN…VIN, lado do sonar; 10º pino contando a partir da ponta do USB)
  - Fio 33 — vermelho — 26 AWG — corte com 100 mm
      de: ponte H TB6612, furo BIN2 (fileira de controle, a do PWMA; 6º furo)
      para: ESP32, pino D33 (fileira da FRENTE, a do EN…VIN, lado do sonar; 9º pino contando a partir da ponta do USB)
  - Fio 34 — vermelho — 26 AWG — corte com 80 mm
      de: ponte H TB6612, furo PWMB (fileira de controle, a do PWMA; 7º furo)
      para: ESP32, pino D14 (fileira da FRENTE, a do EN…VIN, lado do sonar; 5º pino contando a partir da ponta do USB)

----------------------------------------------------------------------------------------------------
PASSO 42 de 66 · Bloco 9 · Grave o código antes de soldar
----------------------------------------------------------------------------------------------------
Imagem: nenhuma (passo só de texto)
Peças deste passo:
  - 1× Cabo USB de dados
O que fazer:
  * Com o ESP32 solto, ligue no computador e grave o código com MODO_TESTE = true (passo a passo no
    bloco 13).
  * Depois de montado, o USB fica encostado na ponte H e o cabo pode não entrar.
CONFIRA: O LED azul da placa pisca depois de gravar.
Quando terminar: passo 42 feito. Próximo: passo 43.
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

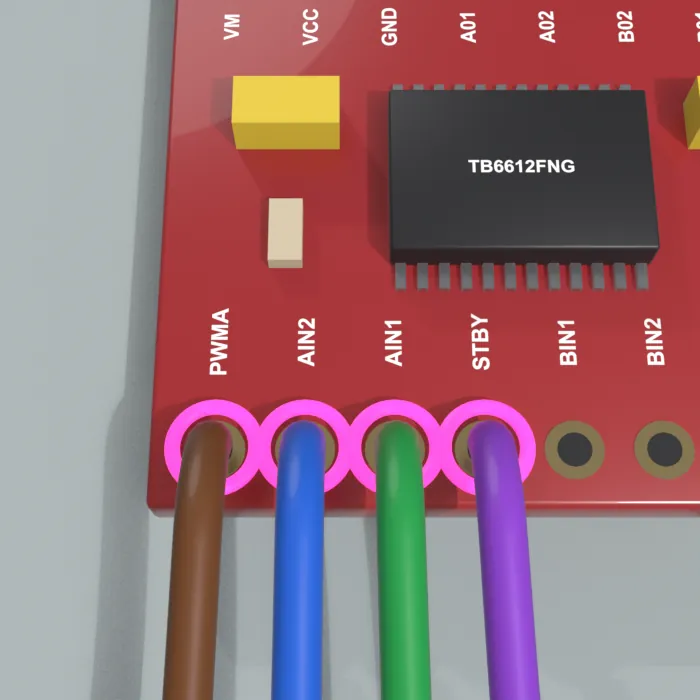
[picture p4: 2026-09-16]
docs/manual/ponteh-g6-lupa.webp

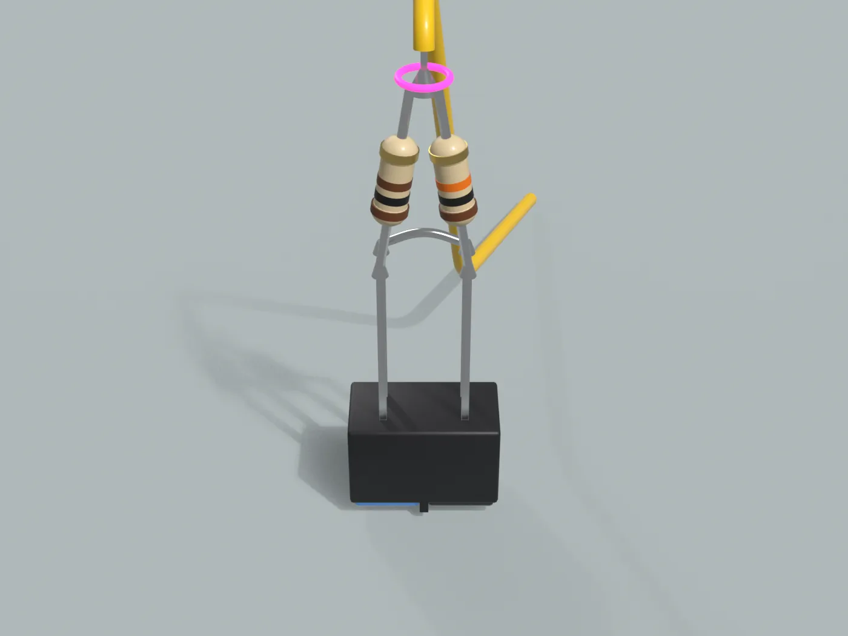
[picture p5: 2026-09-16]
docs/manual/tcrt-t4.webp

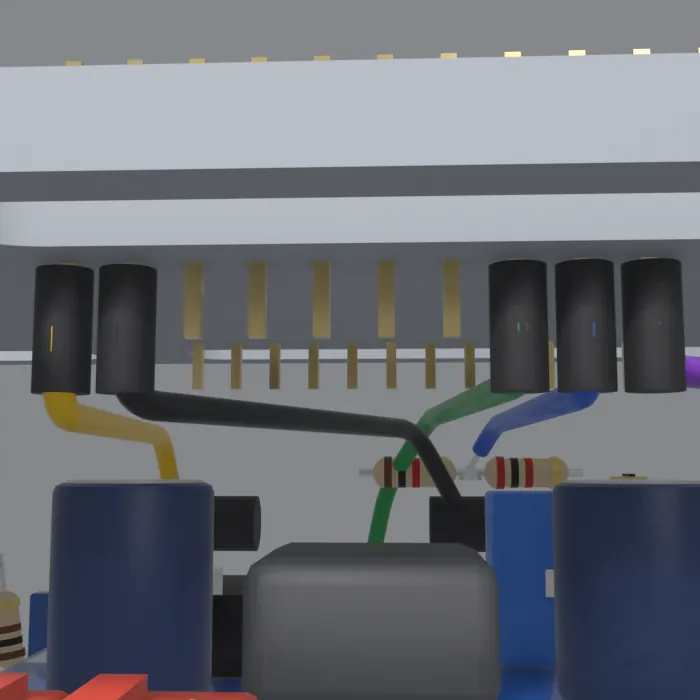
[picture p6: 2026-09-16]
docs/manual/robo-esp-tras-lupa.webp

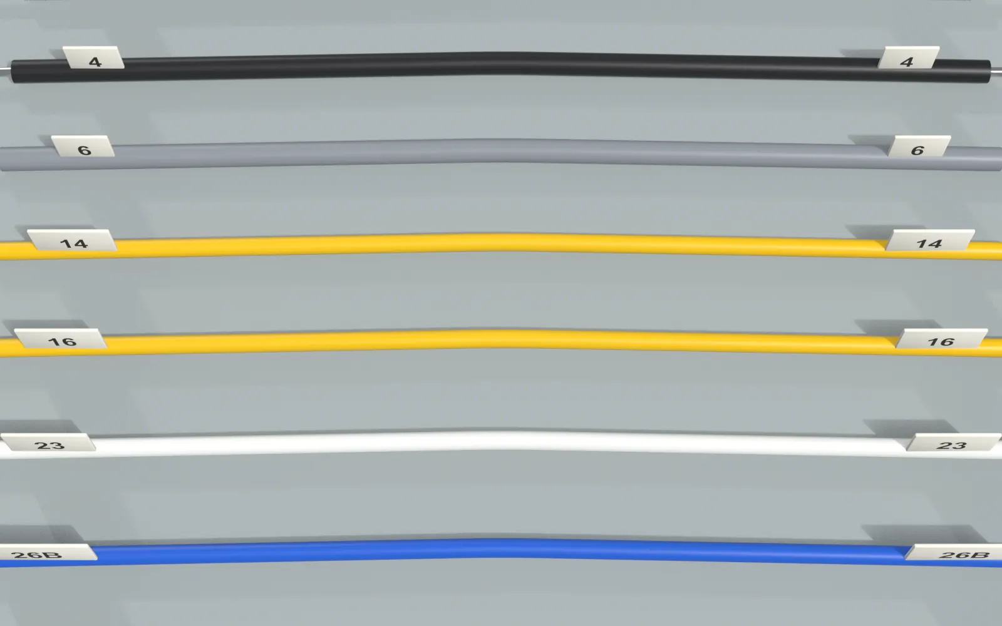
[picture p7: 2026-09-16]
docs/manual/preparo-fios.webp

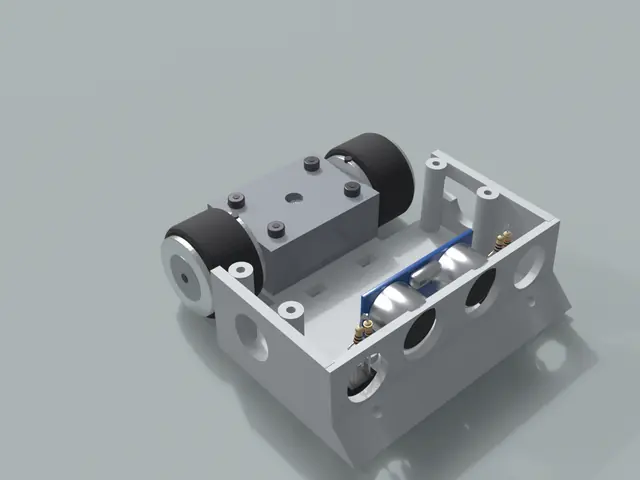
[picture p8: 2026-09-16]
docs/manual/robo-rodas-mini.webp

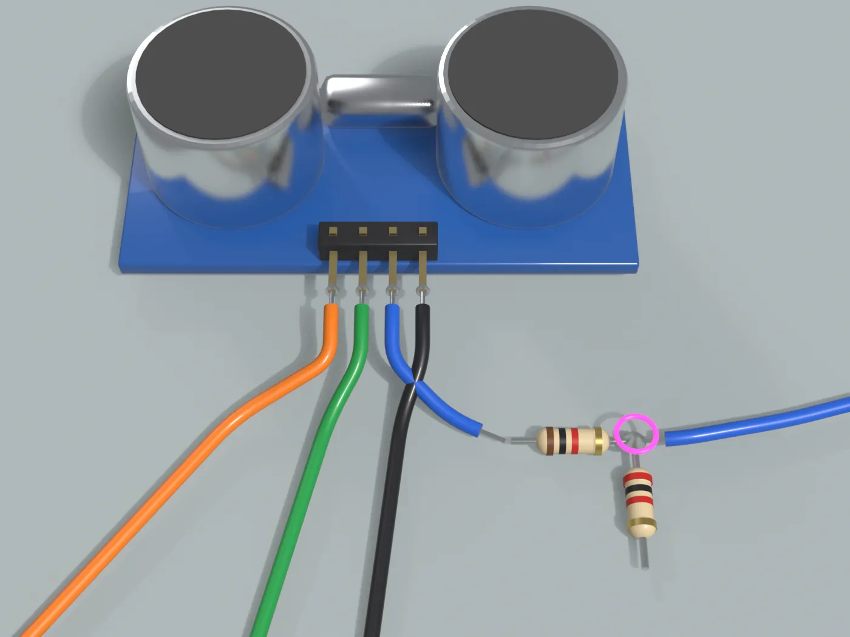
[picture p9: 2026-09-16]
docs/manual/sonar-h5.webp

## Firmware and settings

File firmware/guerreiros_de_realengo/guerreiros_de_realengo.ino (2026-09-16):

/* =============================================================================
   GUERREIROS DE REALENGO  ·  firmware de mini sumo  ·  InovaWeek UVV
   -----------------------------------------------------------------------------
   Placa   : ESP32 DevKit V1, 30 pinos   (Arduino core "esp32" 3.3.x)
   Ponte H : TB6612FNG
   Sensores: HC-SR04 (acha o adversario) + 2x TCRT5000 (borda branca)
             + receptor IR VS1838B/KY-022 (sinal do juiz)

   NINGUEM DIRIGE O ROBO. O controle fica com o juiz, que aponta para os
   dois robos e da o START ao mesmo tempo (e o STOP no fim).
     chave ligada -> espera o START do juiz (mede o preto enquanto espera)
     -> START -> ESPERA_APOS_START -> gira procurando o adversario -> ataca
     -> se um sensor ver a borda branca, recua e gira de volta para o centro
     -> STOP do juiz: para na hora.

   Biblioteca: IRremote (Armin Joachimsmeyer) 4.7 ou superior
   Arduino IDE -> Gerenciador de Bibliotecas -> procurar "IRremote"

   ESQUERDA e DIREITA sao sempre do ponto de vista do ROBO:
   robo na mesa, frente (o sonar) apontando para longe de voce.

   SENSOR DE LINHA: TCRT5000 avulso (4 pernas) + resistores de 100 ohm e 10 k.
   O BRANCO da borda puxa a leitura para BAIXO.

   CHAVE SS12D00 (0,5 A): liga so a eletronica. A ponte H recebe a bateria
   direto; com a chave desligada o ESP32 apaga e os motores ficam parados.
   Com o cabo USB ligado, deixe a chave em DESLIGA.

   ANTES DE RODAR:
     1. Ajuste o LM2596 para 5,00 V com multimetro. So depois ligue o ESP32.
     2. Grave com MODO_TESTE = true e abra o Monitor Serial a 115200.
     3. Aponte o controle do juiz, aperte START e depois STOP e anote os
        codigos que aparecem. Preencha IR_START e IR_STOP.
     4. Ponha o robo no preto e depois na borda branca. Veja os numeros da linha.
        Preto tem que dar bem mais que branco (ex.: 3000 contra 300).
     5. Com o robo NO AR, digite  e  (motor esquerdo) e  d  (motor direito)
        no Monitor Serial. Cada roda deve girar PARA A FRENTE.
        Se girar para tras, troque os dois fios daquele motor na TB6612.
     6. Confira no regulamento se o robo precisa esperar 5 s depois do START
        e ajuste ESPERA_APOS_START. Coloque MODO_TESTE = false e regrave.
   ============================================================================= */

#include <IRremote.hpp>

// ---------------------------------------------------------------- MODO TESTE
// true  = os motores so giram quando voce manda (e / d) pelo cabo USB
// false = modo de combate
const bool MODO_TESTE = true;

// ------------------------------------------------------------------- PINAGEM
// TB6612FNG  (canal A = motor ESQUERDO, canal B = motor DIREITO)
const int PIN_AIN1 = 26;
const int PIN_AIN2 = 27;
const int PIN_PWMA = 25;
const int PIN_BIN1 = 32;
const int PIN_BIN2 = 33;
const int PIN_PWMB = 14;
const int PIN_STBY = 13;   // HIGH habilita a ponte H

// HC-SR04  (ECHO passa pelo divisor 1 k / 2 k: 5 V -> 3,3 V)
const int PIN_TRIG = 5;
const int PIN_ECHO = 18;

// TCRT5000  (34 e 35 sao entradas analogicas do ADC1, so-entrada)
const int PIN_LINHA_ESQ = 34;
const int PIN_LINHA_DIR = 35;

// Receptor IR do juiz e LED azul da placa
const int PIN_IR  = 19;
const int PIN_LED = 2;

// -------------------------------------------------------------- AJUSTE FINO
const int PWM_FREQ = 20000;   // 20 kHz: fora da faixa audivel, motor nao chia
const int PWM_RES  = 8;       // resolucao 8 bits -> 0 a 255

const int VEL_ATAQUE = 255;   // empurrando o oponente
const int VEL_BUSCA  = 165;   // girando a procura
const int VEL_RECUO  = 210;   // fugindo da borda
const int VEL_TESTE  = 140;   // teste de motor no MODO_TESTE

const int DIST_ALVO_CM  = 45; // acima disso, considera que nao ha oponente
const int CONFIRMA_ALVO = 2;  // leituras seguidas para aceitar a deteccao

// Espera entre o START do juiz e a largada.
// 5000 = 5 s (regra classica). Se o regulamento deixar sair na hora do sinal, use 0.
const unsigned long ESPERA_APOS_START = 5000;

const unsigned long T_RECUO     = 320;   // ms recuando ao ver a linha
const unsigned long T_GIRO_FUGA = 380;   // ms girando depois do recuo
const unsigned long T_VARRER    = 600;   // ms girando para cada lado na busca
const unsigned long T_PING      = 60;    // intervalo entre disparos do sonar

// ---------------------------------------------------------- SENSOR DE LINHA
// Leitura de 0 a 4095. Abaixo do limiar = BRANCO (borda).
// Enquanto espera o START, o robo acompanha a leitura do preto embaixo dele
// e, na largada, usa FRACAO_DO_PRETO dessa leitura como limiar de cada sensor.
const bool  CALIBRAR_NA_LARGADA = true;
const int   LIMIAR_PADRAO       = 2000;   // usado sem calibracao ou se ela falhar
const float FRACAO_DO_PRETO     = 0.55;
const int   PRETO_MINIMO        = 1200;   // preto medido abaixo disso = algo errado

int limiarEsq = LIMIAR_PADRAO;
int limiarDir = LIMIAR_PADRAO;

// Codigos do controle do juiz. Descubra os seus com MODO_TESTE = true.
uint16_t IR_START = 0x0040;
uint16_t IR_STOP  = 0x0041;

// ------------------------------------------------------------ SONAR SEM TRAVA
// Le o HC-SR04 por interrupcao. O loop nunca fica parado esperando o eco,
// o que importa muito num sumo: 25 ms parado e o oponente ja te empurrou.
volatile unsigned long ecoInicio  = 0;
volatile unsigned long ecoDuracao = 0;
volatile bool          ecoPronto  = false;

void IRAM_ATTR trataEco() {
  if (digitalRead(PIN_ECHO)) {
    ecoInicio = micros();
  } else if (ecoInicio) {
    ecoDuracao = micros() - ecoInicio;
    ecoInicio  = 0;
    ecoPronto  = true;
  }
}

unsigned long ultimoPing = 0;
int distanciaCm = 999;
int alvoSeguido = 0;

void atualizaSonar() {
  unsigned long agora = millis();

  if (agora - ultimoPing >= T_PING) {
    ultimoPing = agora;
    ecoPronto  = false;
    digitalWrite(PIN_TRIG, LOW);
    delayMicroseconds(3);
    digitalWrite(PIN_TRIG, HIGH);
    delayMicroseconds(10);
    digitalWrite(PIN_TRIG, LOW);
  }

  if (ecoPronto) {
    ecoPronto = false;
    int d = ecoDuracao / 58;                 // us -> cm
    distanciaCm = (d < 2 || d > 400) ? 999 : d;
  } else if (agora - ultimoPing > T_PING * 3) {
    distanciaCm = 999;                       // sonar mudo: assume campo livre
  }

  // Exige leituras seguidas antes de confiar. Corta falso positivo de eco.
  if (distanciaCm <= DIST_ALVO_CM) {
    if (alvoSeguido < CONFIRMA_ALVO) alvoSeguido++;
  } else {
    alvoSeguido = 0;
  }
}

bool temAlvo() { return alvoSeguido >= CONFIRMA_ALVO; }

// ---------------------------------------------------------------- MOTORES
void acionaMotor(int in1, int in2, int pinPwm, int vel) {
  bool re = (vel < 0);
  int  v  = constrain(abs(vel), 0, 255);
  digitalWrite(in1, re ? LOW  : HIGH);
  digitalWrite(in2, re ? HIGH : LOW);
  ledcWrite(pinPwm, v);
}

void mover(int esq, int dir) {
  if (MODO_TESTE) return;                    // no teste, so gira quando voce manda
  acionaMotor(PIN_AIN1, PIN_AIN2, PIN_PWMA, esq);
  acionaMotor(PIN_BIN1, PIN_BIN2, PIN_PWMB, dir);
}

void parar() {
  acionaMotor(PIN_AIN1, PIN_AIN2, PIN_PWMA, 0);
  acionaMotor(PIN_BIN1, PIN_BIN2, PIN_PWMB, 0);
}

// ------------------------------------------------------------ SENSOR DE LINHA
int leLinha(int pino) {
  return (analogRead(pino) + analogRead(pino)) / 2;   // media de 2 corta ruido
}

bool linhaEsq() { return leLinha(PIN_LINHA_ESQ) < limiarEsq; }
bool linhaDir() { return leLinha(PIN_LINHA_DIR) < limiarDir; }

// Media movel do preto: acompanha o chao embaixo do robo enquanto ele espera.
float pretoEsq = 0, pretoDir = 0;
bool  temPreto = false;

void acompanhaPreto() {
  static unsigned long ultima = 0;
  if (millis() - ultima < 20) return;        // 50 amostras por segundo
  ultima = millis();
  int e = leLinha(PIN_LINHA_ESQ), d = leLinha(PIN_LINHA_DIR);
  if (!temPreto) { pretoEsq = e; pretoDir = d; temPreto = true; return; }
  pretoEsq += 0.05 * (e - pretoEsq);         // constante de tempo ~1 s
  pretoDir += 0.05 * (d - pretoDir);
}

int limiarDe(float preto, const char *lado) {
  Serial.print(F("preto ")); Serial.print(lado); Serial.print(F(" = ")); Serial.print((int)preto);
  if (preto < PRETO_MINIMO) {
    Serial.println(F("  -> baixo demais, usando LIMIAR_PADRAO (confira fios e altura do sensor)"));
    return LIMIAR_PADRAO;
  }
  int limiar = constrain((int)(preto * FRACAO_DO_PRETO), 400, 3500);
  Serial.print(F("  -> limiar ")); Serial.println(limiar);
  return limiar;
}

void fechaCalibracao() {
  if (!CALIBRAR_NA_LARGADA || !temPreto) return;
  limiarEsq = limiarDe(pretoEsq, "esq");
  limiarDir = limiarDe(pretoDir, "dir");
}

// ---------------------------------------------------------- MAQUINA DE ESTADOS
enum Estado { PARADO, PREPARANDO, BUSCANDO, ATACANDO, RECUANDO, GIRANDO_FUGA };

Estado        estado     = PARADO;
unsigned long marcaTempo = 0;    // inicio do estado atual
int           ladoFuga   = 1;    // 1 = gira p/ direita, -1 = p/ esquerda
int           ladoBusca  = 1;

void trocaEstado(Estado novo) {
  estado     = novo;
  marcaTempo = millis();
}

void largada() {                 // fim da espera: calibra e sai procurando
  fechaCalibracao();
  digitalWrite(PIN_LED, HIGH);
  trocaEstado(BUSCANDO);
}

// ------------------------------------------------------------- MODO TESTE
void testeMotor(bool esquerdo) {
  Serial.println(esquerdo ? F("motor ESQUERDO para frente") : F("motor DIREITO para frente"));
  if (esquerdo) acionaMotor(PIN_AIN1, PIN_AIN2, PIN_PWMA, VEL_TESTE);
  else          acionaMotor(PIN_BIN1, PIN_BIN2, PIN_PWMB, VEL_TESTE);
  delay(700);
  parar();
}

void rodaModoTeste() {
  while (Serial.available()) {
    char c = Serial.read();
    if (c == 'e') testeMotor(true);
    if (c == 'd') testeMotor(false);
    if (c == 'c') {                              // calibra agora, com o robo no preto
      long se = 0, sd = 0;
      for (int i = 0; i < 60; i++) { se += leLinha(PIN_LINHA_ESQ); sd += leLinha(PIN_LINHA_DIR); delay(5); }
      pretoEsq = se / 60.0; pretoDir = sd / 60.0; temPreto = true;
      fechaCalibracao();
    }
  }

  static unsigned long ultimoLog = 0;
  if (millis() - ultimoLog < 300) return;
  ultimoLog = millis();
  int e = leLinha(PIN_LINHA_ESQ), d = leLinha(PIN_LINHA_DIR);
  Serial.print(F("dist ")); Serial.print(distanciaCm); Serial.print(F(" cm"));
  Serial.print(F(" | alvo ")); Serial.print(temAlvo() ? "SIM" : "nao");
  Serial.print(F(" | linha esq ")); Serial.print(e); Serial.print(e < limiarEsq ? " BRANCO" : " preto");
  Serial.print(F(" | dir "));       Serial.print(d); Serial.print(d < limiarDir ? " BRANCO" : " preto");
  Serial.print(F(" | limiar ")); Serial.print(limiarEsq); Serial.print('/'); Serial.println(limiarDir);
}

// --------------------------------------------------------------------- SETUP
void setup() {
  Serial.begin(115200);

  pinMode(PIN_AIN1, OUTPUT); pinMode(PIN_AIN2, OUTPUT);
  pinMode(PIN_BIN1, OUTPUT); pinMode(PIN_BIN2, OUTPUT);
  pinMode(PIN_STBY, OUTPUT); digitalWrite(PIN_STBY, HIGH);
  pinMode(PIN_LED,  OUTPUT);

  ledcAttach(PIN_PWMA, PWM_FREQ, PWM_RES);
  ledcAttach(PIN_PWMB, PWM_FREQ, PWM_RES);
  parar();

  pinMode(PIN_TRIG, OUTPUT); digitalWrite(PIN_TRIG, LOW);
  pinMode(PIN_ECHO, INPUT);
  attachInterrupt(digitalPinToInterrupt(PIN_ECHO), trataEco, CHANGE);

  analogReadResolution(12);                  // 0 a 4095
  analogSetAttenuation(ADC_11db);            // faixa ate ~3,1 V

  IrReceiver.begin(PIN_IR, DISABLE_LED_FEEDBACK);

  Serial.println();
  Serial.println(F("Guerreiros de Realengo - pronto"));
  Serial.println(MODO_TESTE ? F("MODO TESTE: e / d giram um motor, c calibra, controle mostra os codigos")
                            : F("MODO COMBATE: aguardando o START do juiz"));
}

// ---------------------------------------------------------------------- LOOP
void loop() {
  atualizaSonar();

  // -------- sinal do juiz: so START e STOP --------
  if (IrReceiver.decode()) {
    uint16_t cmd = IrReceiver.decodedIRData.command;

    if (MODO_TESTE) {
      Serial.print(F("IR recebido -> protocolo "));
      Serial.print(getProtocolString(IrReceiver.decodedIRData.protocol));
      Serial.print(F("  endereco 0x")); Serial.print(IrReceiver.decodedIRData.address, HEX);
      Serial.print(F("  comando 0x"));  Serial.println(cmd, HEX);
    }

    if (cmd == IR_START && estado == PARADO) {
      Serial.println(F("START do juiz"));
      trocaEstado(PREPARANDO);
      if (ESPERA_APOS_START == 0 && !MODO_TESTE) largada();
    } else if (cmd == IR_STOP) {
      trocaEstado(PARADO);
      parar();
      Serial.println(F("STOP do juiz"));
    }
    IrReceiver.resume();
  }

  // -------- modo teste: so relata --------
  if (MODO_TESTE) {
    rodaModoTeste();
    return;
  }

  unsigned long dt = millis() - marcaTempo;

  // -------- a borda tem prioridade sobre tudo --------
  // Sair do dohyo e derrota imediata. Nenhum ataque vale mais que isso.
  if (estado == BUSCANDO || estado == ATACANDO) {
    bool e = linhaEsq(), d = linhaDir();
    if (e || d) {
      ladoFuga = (e && !d) ? 1 : (d && !e) ? -1 : ladoFuga;
      trocaEstado(RECUANDO);
    }
  }

  switch (estado) {

    case PARADO:                                     // esperando o juiz
      parar();
      acompanhaPreto();
      digitalWrite(PIN_LED, (millis() / 500) % 2);   // pisca devagar
      break;

    case PREPARANDO:                                 // START recebido, contando
      parar();
      acompanhaPreto();
      digitalWrite(PIN_LED, (millis() / 120) % 2);   // pisca rapido
      if (dt >= ESPERA_APOS_START) largada();
      break;

    case BUSCANDO:
      if (temAlvo()) {
        trocaEstado(ATACANDO);
        break;
      }
      // Gira no proprio eixo, alternando o lado, ate achar alguem.
      mover(VEL_BUSCA * ladoBusca, -VEL_BUSCA * ladoBusca);
      if (dt >= T_VARRER) {
        ladoBusca = -ladoBusca;
        marcaTempo = millis();
      }
      break;

    case ATACANDO:
      if (!temAlvo()) {
        ladoBusca = ladoFuga;          // continua procurando para onde ele foi
        trocaEstado(BUSCANDO);
        break;
      }
      mover(VEL_ATAQUE, VEL_ATAQUE);   // toca para cima, sem freio
      break;

    case RECUANDO:
      mover(-VEL_RECUO, -VEL_RECUO);
      if (dt >= T_RECUO) trocaEstado(GIRANDO_FUGA);
      break;

    case GIRANDO_FUGA:
      mover(VEL_RECUO * ladoFuga, -VEL_RECUO * ladoFuga);
      if (dt >= T_GIRO_FUGA) {
        ladoBusca = ladoFuga;
        trocaEstado(BUSCANDO);
      }
      break;
  }
}

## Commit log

2026-09-10 Robo de mini sumo Guerreiros de Realengo: STL de impressao, firmware do ESP32, manual de montagem, video, diagramas de fiacao e README
    [IMPRESSAO-1-chassi.3mf, IMPRESSAO-1-chassi.stl, IMPRESSAO-2-restante.3mf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]
2026-09-10 Site: manual de montagem como index.html na raiz para o GitHub Pages
2026-09-10 Robo 100% autonomo: sem receptor IR, largada pela chave com 5 s de espera; manual, site, diagramas e README atualizados
2026-09-10 Largada pelo controle do juiz: receptor IR de volta so para START e STOP, espera configuravel e calibracao enquanto aguarda
2026-09-16 Manual estilo LEGO com a montagem real: 65 passos, fio a fio, para celular
    - Site refeito: um passo por vez (modo montagem com deslizar e continuar de onde parou), imagens do Blender com o numero de cada fio, anel onde soldar, lupa com o nome dos furos, busca "achar fio" e 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
    - Sensor de borda TCRT5000 de 4 pernas em todas as imagens (sem o modulo)
    - Disposicao do grupo: ESP32 e ponte H em cima da plataforma (USB para a esquerda), LM2596 em cima da bateria, plataforma 12 mm mais alta (M3 x 40), receptor do juiz no furo direito
    - Chave SS12D00 (0,5 A) so na eletronica: fio 3 leva a bateria direto ao VM da ponte H; fio 5 sai do conector para o IN- do LM2596
    - Divisor do EC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
    [robo-sumo.blend]
2026-09-16 Manual por blocos em cards: versão do grupo e completa, português e inglês, claro e escuro; ESP32 com pinos nos rasgos e fios soldados por baixo
    - index.html e en.html: versão do grupo (fio vermelho e preto; sonar, receptor e motores já soldados)
    - completo.html e complete-en.html: fios coloridos, tudo soldado do zero
    - cada bloco abre com os fios que usa e o tamanho de corte; um passo por tela
    - ESP32 apoiado na plataforma com os pinos atravessando dois rasgos; fios na ponta do pino, por baixo, com termorretrátil
    - ponte H: fios de controle na bancada, descendo pelo rasgo R2; energia e motores no bloco 11
    - plataforma +17 mm (espaçador de 12 mm + 5 mm), capô com M3 x 45
    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
    [robo-sumo.blend]
2026-09-16 Versão com fios coloridos como padrão (index.html e en.html) e a do grupo em grupo.html; idioma pelas bandeiras do Brasil e dos EUA e tema por ícone de sol e lua
    - completo.html e complete-en.html redirecionam para index.html e en.html mantendo o bloco aberto
2026-09-16 Manual em texto em docs/montagem-texto para perguntar a um chat no dia da montagem
    - 00-LEIA-PRIMEIRO: como usar, instruções para o assistente, convenções, onde fica cada peça, alimentação, regras e pontos não confirmados
    - 01 e 02: passo a passo completo das versões colorida e do grupo, com imagem, peças, fio a fio, avisos e conferências
    - 03 a 06: lista dos 36 fios, ligações por peça (30 pinos do ESP32 contados do USB), conferências com multímetro e firmware
    - gerado das mesmas fontes do site (títulos dos passos e cortes conferidos contra index.html e grupo.html)
2026-09-16 Vídeo da montagem com o ESP32 soldado nos pinos por baixo e a plataforma em 17 mm, com capítulos por bloco nas 4 páginas
2026-10-22 Licença MIT para o código, o manual e os arquivos próprios; o chassi derivado de STL de terceiros fica de fora
